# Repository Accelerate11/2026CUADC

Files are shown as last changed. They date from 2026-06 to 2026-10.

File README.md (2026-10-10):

# 2026CUADC
哈尔滨工业大学2026CUADC多旋翼无人机侦察与救援项目组备赛日志

2025年末我接手了航协多旋翼无人机侦察与救援项目组，并开始了在先前基础上的新一轮备赛，记录此文档来做详细的技术路线备份和日志书写，方便后人学习使用，也欢迎各位技术大佬与我联系进行交流和批评指正

2026.8.11  辽宁·沈阳  2026CUADC北部赛区冠军

2026.10.08  四川·自贡  2026CUADC国赛 一机组1338分（国一）  二机组1341分（国一） 团体第四（国三）

感谢CUAV雷迅创新对本项目的大力支持！

感谢micoair微空科技对本项目的大力支持！

感谢HARD海砥装备对本项目的大力支持！

屏幕截图 2026-09-11 192442

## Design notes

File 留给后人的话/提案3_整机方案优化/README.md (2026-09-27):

# 结构方面，参考大连理工大学结构，做非常规构型四旋翼、使用高能量密度高压大容量电池，提升整体续航，将机身结构直接纳入桨保部分，参考这些优秀结构：
屏幕截图 2026-09-27 121436
屏幕截图 2026-09-27 121443
屏幕截图 2026-09-27 121426
屏幕截图 2026-09-27 121419
屏幕截图 2026-09-27 121408
屏幕截图 2026-09-27 121359
# 硬件方面，更换更稳定的4G模块，考虑使用更强的机载算力，有钱或者有资源建议使用orin NX 更新飞控、RTK设备，RTK基站有条件的话买两套，更换大功率数传
# 算法方面，提升代码结构，可以考虑使用Behavior Tree，危险物识别阶段，如果能训练出高速情况下的快速准确识别模型采用视觉模型会更好

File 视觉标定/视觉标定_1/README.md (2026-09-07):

# Vision-Servo Payload Alignment Toolkit

一个面向 ROS 2 的**视觉对准 / 投放中心标定框架**。这个公开版刻意不提供任何目标检测模型，也不绑定 RealSense、YOLO 或某一类视觉算法；核心只保留最有复用价值的部分：

- 把视觉节点输出统一成一个很薄的 ROS 2 接口；
- 把“目标中心准星”和“载荷真实投放中心准星”从视觉算法里拆出来；
- 支持低位铅垂线人工对准，稳健求解每个载荷在 FCU `FRD` 机体系中的有效 `X/Y`；
- 支持高位真实落点试验，用中位数 + MAD 修正静态投放中心；
- 可选保留 MAVROS 舵机地面循环测试。

> 这个仓库的原则是：**视觉节点只负责“我看到了什么、目标在机体系哪里”；准星、人工标定和投放中心几何由独立节点负责。**

## 1. 架构

```text
camera driver / your image source
       │
       ├── sensor_msgs/Image ───────────────┐
       ├── sensor_msgs/CameraInfo ──────────┤
       │                                    │
       ▼                                    ▼
YOUR VISION NODE                    alignment_viewer
(完全由使用者实现)                  绿色：目标中心
       │                             彩色：各载荷投放中心投影
       │ PoseArray / FRD                    │
       └── /vision_servo/targets_body ──────┘
                      │
                      └── 可同时给你自己的飞行/伺服控制节点使用
```

公开版不再包含旧工程中的检测模型、检测器实现和比赛专用全流程状态机。视觉接口和准星显示彻底解耦，因此别人可以直接接自己的 YOLO、传统 CV、AprilTag、深度相机、双目、VIO 或其他目标定位节点。

## 2. ROS 2 视觉接口

默认目标话题：

```text
/vision_servo/targets_body
```

类型：

```text
geometry_msgs/msg/PoseArray
```

约定：

- `header.stamp`：该帧图像的**采集时间**，必须非零；
- `header.frame_id`：默认 `fcu_body_frd`；
- `pose.position.{x,y,z}`：目标参考点在 FCU body FRD 下的位置，单位 m；
- `pose.orientation.x`：目标直径/尺度，可不用，填 `0.0`；
- `pose.orientation.y`：置信度 `[0,1]`，不知道时填 `1.0`；
- `pose.orientation.z`：可选深度诊断值，不用填 `0.0`；
- `pose.orientation.w`：接口版本哨兵，填 `1.0`。

坐标固定使用 FCU/MAVLink `FRD`：

- `+X`：机头前；
- `+Y`：机体右；
- `+Z`：向下。

完整说明见 [`docs/VISION_INTERFACE.md`](docs/VISION_INTERFACE.md)。

## 3. 为什么准星必须独立于视觉节点

原来最有价值的思路并不是某一个检测模型，而是两套几何量同时显示：

1. **目标中心**：视觉节点给出的目标三维位置投影到当前相机画面；
2. **Payload projection**：每个载荷在机体上的标定 `X/Y` 垂线，与当前目标对准平面的交点再投回相机画面。

两者只有在真实载荷投放中心位于目标正上方时才应重合。载荷准星不能从目标 `x/y` 生成，否则准星会“跟着目标跑”，反而把对准误差隐藏掉。

公开版中的 `alignment_viewer` 只依赖：

- 相机图像 + `CameraInfo`；
- `camera -> FCU body FRD` 外参；
- 视觉节点发布的目标 FRD 坐标；
- 每个载荷的 FRD 投放中心。

因此检测算法可以被完全替换。

## 4. 快速开始

环境建议：Ubuntu 22.04 + ROS 2 Humble。

### 4.1 准备配置

```bash
cp config/aircraft.example.yaml config/aircraft.yaml
# 编辑 config/aircraft.yaml
python3 tools/validate_config.py --config config/aircraft.yaml --mode alignment
python3 tools/generate_config.py
```

最关键的配置是：

```yaml
camera:
  image_topic: /camera/color/image_raw
  camera_info_topic: /camera/color/camera_info
  rotation_camera_to_frd: [... 9 values ...]
  translation_frd_m: [x, y, z]

vision:
  detections_topic: /vision_servo/targets_body
  frame_id: fcu_body_frd

payloads:
  release_offsets_frd_m:
    [x1, y1, z1,
     x2, y2, z2]

target:
  # 视觉发布的参考点到真正“对准平面”的竖直高度。
  # 例如视觉发布桶底/地面中心，而桶口高 0.30 m，则填 0.30。
  # 若视觉已经直接发布桶口平面上的 3D 点，则填 0.0。
  height_m: 0.30
```

### 4.2 编译

```bash
./bin/build.sh
```

### 4.3 启动你的相机和视觉节点

公开版**不会替你启动相机，也不会加载任何模型**。先启动你自己的相机节点，再启动你自己的视觉节点，使其持续发布上述 `PoseArray`。

仓库内提供一个空模板：

```bash
./bin/run_vision_template.sh
```

真正接入时通常直接复制 `vision_provider_template.py`，把 `detect_targets_body_frd()` 函数替换成自己的算法即可；如果你已经有独立节点，只要话题格式满足契约，模板完全不用运行。

先检查接口：

```bash
./bin/check_vision_contract.sh
```

### 4.4 启动准星画面

```bash
./bin/visual_alignment.sh
```

画面会显示：

- 绿色十字：视觉目标中心；
- 不同颜色十字：各 Payload 的真实投放中心在当前目标平面上的投影；
- `+X FWD` / `+Y RIGHT`：当前配置对应的机体系方向；
- 每个 Payload 的 `dF / dR` 误差。

本脚本只启动准星显示节点，不启动飞控、不解锁、不飞行。

## 5. 静态投放中心标定

以 Payload 1 为例：

1. 低位固定飞机并保持姿态稳定；
2. 从真实投放机构中心垂下铅垂线；
3. 人工移动整架飞机，让铅垂线落到目标中心；
4. 保持 3 秒以上；
5. 退出 `visual_alignment.sh`；
6. 使用这一轮自动保存的检测 CSV：

```bash
python3 tools/estimate_static_offsets.py \
  logs/static_alignment_YYYYMMDD_HHMMSS/detections.csv \
  --payload 1 \
  --aircraft config/aircraft.yaml \
  --last-seconds 3 \
  --write
```

脚本用最近稳定窗口的 FRD `X/Y` 中位数作为该载荷的静态投放中心，**不会修改 Z**。Z 仍应由机械测量获得。

然后重新生成准星参数：

```bash
python3 tools/generate_config.py
```

对 Payload 2 重复一次。

## 6. 高位真实落点修正

静态几何不能覆盖舵机释放延迟、瓶体摆动、残余水平速度、气流等误差。真实投放后按 FRD 方向记录第一落点相对目标中心的偏差：

```bash
python3 tools/record_drop_trial.py \
  --payload 1 \
  --height 0.8 \
  --miss-forward 0.03 \
  --miss-right -0.02 \
  --output logs/drop_trials.csv
```

每个载荷、每个最终使用高度建议至少 3 次，再求解：

```bash
python3 tools/solve_drop_trials.py \
  logs/drop_trials.csv \
  --aircraft config/aircraft.yaml \
  --output logs/drop_solution.yaml
```

规则：

```text
recommended XY = static XY + median landing miss XY
```

同时输出 MAD 作为重复性指标。

## 7. 舵机地面检查（可选）

如果你仍使用 MAVROS/ArduPilot，并在 `aircraft.yaml` 中填写了 FCU 与舵机参数，可在**卸桨、飞控未解锁**状态运行：

```bash
./bin/servo_ground_check.sh
```

这部分与准星/视觉接口相互独立，不需要使用。

## 8. 目录

```text
config/
  aircraft.example.yaml       用户唯一需要维护的物理/话题配置模板
  alignment_base.yaml         准星节点基础参数
bin/
  build.sh                    编译 ROS 2 工作区
  visual_alignment.sh         只启动独立准星节点
  run_vision_template.sh      启动“空视觉节点”模板
  check_vision_contract.sh    检查别人接入的视觉节点是否满足接口
  servo_ground_check.sh       可选 MAVROS 舵机地面测试
tools/
  generate_config.py
  validate_config.py
  estimate_static_offsets.py
  record_drop_trial.py
  solve_drop_trials.py
  servo_cycle_test.py
ros2_ws/src/vision_servo_calibration/
  vision_servo_calibration/alignment_viewer_node.py
  vision_servo_calibration/vision_provider_template.py
  vision_servo_calibration/vision_contract_check.py
  vision_servo_calibration/projection.py
  launch/alignment.launch.py
docs/
  VISION_INTERFACE.md
  DESIGN.md
  MIGRATION_FROM_OLD_WORKSPACE.md
```

## 9. 发布到 GitHub 前

`.gitignore` 已排除：

- `build/install/log`；
- `config/aircraft.yaml`；
- 生成参数；
- 飞行/标定日志；
- Python 缓存。

这个公开版也已经移除原始检测模型、ONNX/PT 文件、原视觉算法和比赛专用全流程节点。请在正式发布前自行选择并写入开源许可证；本整理版没有替项目作者擅自改变许可证。

## 10. 安全边界

本仓库的核心功能是**测量、可视化和标定**。任何自动飞行、自动投放、舵机动作都应由使用者自己的飞行控制程序承担，并自行设置硬件急停、围栏、人工接管和测试流程。

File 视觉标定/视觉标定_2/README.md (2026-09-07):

# CUADC D435i 双投放中心标定工具包

面向当前 CUADC V6X + D435i + ROS 2 Humble 工作空间的**视觉中心 / 双投放口准星标定包**。

本包保留三种可视化方案：

1. **网页模式（推荐 SSH 场景）**：标定画面发布为 ROS Image，经 `web_video_server` + SSH 端口转发，在 Windows/Linux 浏览器查看；
2. **本地显示器模式**：NUC 接显示器时，用独立 `alignment_viewer` 的 OpenCV 窗口或 `rqt_image_view` 查看；
3. **直接视觉节点叠加模式**：当前 `drop_bucket_realsense_node.py` 直接发布 `/cuadc/calib/annotated`，绿色 TARGET + P1/P2 准星与正式识别结果完全同源。

> 安全要求：整个静态标定过程必须卸桨、不解锁、不启动自主飞行状态机。标定只涉及相机、视觉节点和静态机械几何。

---

## 1. 当前坐标系

正式视觉节点使用机体 **FLU**：

```text
+X = 机头前方
+Y = 飞机左侧
+Z = 飞机上方
```

D435i 当前安装方向对应：

```text
图像左边 = 飞机前方
图像右边 = 飞机后方
图像上边 = 飞机右侧
图像下边 = 飞机左侧
相机光轴 = 向下
```

独立 `alignment_viewer` 使用 **FRD**：

```text
+X = 机头前方
+Y = 飞机右侧
+Z = 向下
```

FLU 与 FRD 转换：

```text
X_frd =  X_flu
Y_frd = -Y_flu
Z_frd = -Z_flu
```

---

## 2. 本机当前采用的标定值

当前打包版本记录的是 2026-09-07 这一架 V6X 的候选正式值：

### 相机视觉外参（FLU）

```yaml
camera_offset_body_m: [0.0, 0.0, -0.35]
camera_xy_calib_bias_m: [0.047805, -0.014577]
camera_optical_to_body_rotation:
  [-0.971358, 0.237622, 0.0,
    0.237622, 0.971358, 0.0,
    0.0,      0.0,     -1.0]
```

旋转矩阵行列式应保持约 `+1.000`。

### 双投放口（FLU）

```text
P1 / SERVO9
[+0.0260, -0.0650, -0.3200] m
= 前 2.60 cm、右 6.50 cm、下 32 cm

P2 / SERVO10
[+0.0109, +0.0720, -0.3200] m
= 前 1.09 cm、左 7.20 cm、下 32 cm
```

### 正式投放工作高度

```text
SEARCH        2.2 m
ALIGN_COARSE  1.7 m
ALIGN_FINE    1.3 m
RELEASE       1.3 m
```

> P2 是当前最新候选值。重新拆装相机、投放机构、机架或飞控后必须重新验证。

机器可读记录：`config/cuadc_v6x_current_calibration.yaml`。

---

## 3. 目录结构

```text
README.md
config/
  cuadc_v6x_current_calibration.yaml   当前本机 FLU/FRD 标定记录
  aircraft.example.yaml                通用模板
  aircraft.cuadc_v6x_current.yaml      独立 viewer 的当前 FRD 配置
  alignment_base.yaml
bin/
  build.sh                              编译独立 viewer
  visual_alignment.sh                  原独立 viewer
  visual_alignment_display.sh          本地显示器模式
  visual_alignment_headless.sh         无显示器发布 annotated Image
  web_video_server.sh                  网页视频服务器
  show_annotated_local.sh              rqt_image_view 本地查看
  check_cuadc_calibration_topics.sh     检查 ROS 标定话题
  stop_calibration_helpers.sh           停止辅助进程
  run_current_cuadc_visual_calibration.sh 当前 CUADC 视觉节点标定启动模板
tools/
  sample_payload_xy.py                 5 秒中位数/MAD/剩余误差采样
  apply_current_cuadc_calibration.py   将当前值写入 cuadc_mission
  verify_current_workspace.py          检查工作空间正式值
docs/
  QUICKSTART_CUADC.md
  WEB_VISUALIZATION.md
  DISPLAY_VISUALIZATION.md
  CUADC_VISUAL_NODE_INTEGRATION.md
  COORDINATE_SYSTEMS.md
  CALIBRATION_RECORD_2026_09_07.md
  TROUBLESHOOTING.md
ros2_ws/src/vision_servo_calibration/
  ...                                  独立准星 viewer 源码
```

---

## 4. 推荐方案：当前 CUADC 视觉节点直接叠加 + 网页查看

这是当前无显示器、SSH 使用场景最方便的方案。

### 4.1 安装依赖

```bash
sudo apt update
sudo apt install -y \
  ros-humble-cv-bridge \
  ros-humble-image-transport \
  ros-humble-web-video-server \
  ros-humble-rqt-image-view \
  python3-opencv \
  python3-numpy \
  python3-yaml
```

### 4.2 启动当前视觉标定节点

把本包放到例如：

```text
~/cuadc_mission/calibration/cuadc_d435i_payload_calibration_2026_09_07
```

然后：

```bash
cd ~/cuadc_mission/calibration/cuadc_d435i_payload_calibration_2026_09_07
chmod +x bin/*.sh tools/*.py
./bin/run_current_cuadc_visual_calibration.sh ~/cuadc_mission
```

该脚本使用当前记录的：

- `camera_xy_calib_bias_m`
- `camera_optical_to_body_rotation`
- P1/P2
- 自动曝光
- `/cuadc/calib/annotated`

不会启动状态机，不会启动 MAVROS。

### 4.3 检查标定画面话题

新 SSH 终端：

```bash
cd ~/cuadc_mission/calibration/cuadc_d435i_payload_calibration_2026_09_07
./bin/check_cuadc_calibration_topics.sh
```

至少应看到：

```text
/perception/drop_buckets_body
/cuadc/calib/annotated
```

若已启用完整旁路，还可看到：

```text
/cuadc/calib/color/image_raw
/cuadc/calib/color/camera_info
/vision_servo/targets_body
```

---

## 5. 网页模式（SSH / NUC 无显示器）

### NUC 端

```bash
cd ~/cuadc_mission/calibration/cuadc_d435i_payload_calibration_2026_09_07
./bin/web_video_server.sh
```

默认端口 `8080`。如果 8080 已经被旧的 `web_video_server` 占用，脚本会提示并复用，不要重复启动。

### Windows CMD 端

先获得 NUC 实际 IP：

```bash
hostname -I
```

Windows **CMD** 中必须写一整行，不能用 Linux 的 `\` 换行：

```cmd
ssh -L 8080:127.0.0.1:8080 cuadc@NUC实际IP
```

保持该 CMD 窗口不关闭。

浏览器打开：

```text
http://127.0.0.1:8080/stream?topic=/cuadc/calib/annotated&type=mjpeg
```

画面含义：

```text
绿色 TARGET      = 正式视觉最终输出的桶中心
红/橙 P1         = 1号 / SERVO9 投放口准星
黄/紫 P2         = 2号 / SERVO10 投放口准星
FWD              = 飞机前方
RIGHT            = 飞机右侧
```

---

## 6. 本地显示器模式

NUC 接显示器且有桌面环境时，有两种方式。

### 方式 A：直接查看 `/cuadc/calib/annotated`

```bash
./bin/show_annotated_local.sh
```

底层使用 `rqt_image_view`。

### 方式 B：独立 `alignment_viewer`

先编译：

```bash
./bin/build.sh
```

生成当前 FRD 配置：

```bash
cp config/aircraft.cuadc_v6x_current.yaml config/aircraft.yaml
python3 tools/validate_config.py --config config/aircraft.yaml --mode alignment
python3 tools/generate_config.py
```

然后：

```bash
./bin/visual_alignment_display.sh
```

独立 viewer 会显示：

- 绿色：视觉目标；
- 各 Payload 彩色准星；
- `dF / dR`；
- `+X FWD / +Y RIGHT`；
- 自动记录 CSV 和标注视频。

---

## 7. 无显示器独立 viewer + 网页

如果不想在正式视觉节点里画准星，也可以让独立 viewer 生成：

```text
/vision_servo/alignment/image
```

步骤：

```bash
./bin/visual_alignment_headless.sh
./bin/web_video_server.sh
```

浏览器：

```text
http://127.0.0.1:8080/stream?topic=/vision_servo/alignment/image&type=mjpeg
```

此模式要求视觉侧已经发布：

```text
/cuadc/calib/color/image_raw
/cuadc/calib/color/camera_info
/vision_servo/targets_body
```

详见 `docs/CUADC_VISUAL_NODE_INTEGRATION.md`。

---

## 8. 静态 P1/P2 标定流程

### 8.1 机械条件

- 卸桨；
- 飞机保持水平；
- 正式投放高度建议直接在 `1.3 m` 工作高度验证；
- 桶口高度与比赛桶一致；
- 用铅垂线确定舵机/释放机构真实中轴线。

### 8.2 P1

把桶中心放在 P1 / SERVO9 实际中轴线正下方。

当前 P1 真值：

```text
FLU x=+0.0260 y=-0.0650
```

采样：

```bash
python3 tools/sample_payload_xy.py \
  --payload 1 \
  --true-x 0.0260 \
  --true-y -0.0650 \
  --duration 5
```

输出：

```text
median FLU
MAD
remaining dx
remaining dy
```

目标：

```text
|remaining dx| <= 0.005 m
|remaining dy| <= 0.005 m
```

### 8.3 P2

桶移到 P2 / SERVO10 实际中轴线正下方。

当前候选：

```text
FLU x=+0.0109 y=+0.0720
```

```bash
python3 tools/sample_payload_xy.py \
  --payload 2 \
  --true-x 0.0109 \
  --true-y 0.0720 \
  --duration 5
```

同样建议控制在 5 mm 内；如果已经达到 3~5 mm，停止继续追 1 mm 级噪声。

---

## 9. 如何判断应该调什么

### P1/P2 同方向、近似相同偏差

优先调：

```text
camera_xy_calib_bias_m
```

说明更像相机整体 XY 平移误差。

### P1 与 P2 呈明显相反方向残差

优先检查：

```text
camera_optical_to_body_rotation 的 yaw
```

也要重新核对两个机械中轴线。

### P1 很准，P2 单独不准

不要继续破坏已经正确的相机外参，优先修：

```text
P2 payload_release_offsets_body_m
```

这正是当前这架飞机最后一次调整采用的策略。

### Z 不准

先检查：

```text
飞机参考点高度
桶口真实高度
camera_offset_body_m[2]
depth_reference_mode
```

当前 `rim_direct` 模式下，视觉输出参考点已经是桶沿/桶口平面，不应额外再加 0.30 m。

---

## 10. 把当前标定写入正式 `cuadc_mission`

先预览：

```bash
python3 tools/apply_current_cuadc_calibration.py \
  --workspace ~/cuadc_mission \
  --dry-run
```

确认无误后：

```bash
python3 tools/apply_current_cuadc_calibration.py \
  --workspace ~/cuadc_mission
```

然后检查：

```bash
python3 tools/verify_current_workspace.py \
  --workspace ~/cuadc_mission
```

最后重新编译：

```bash
cd ~/cuadc_mission
source /opt/ros/humble/setup.bash
colcon build --symlink-install --packages-select cuadc_visual_drop_flight
```

---

## 11. 常见问题

### `AMENT_TRACE_SETUP_FILES: unbound variable`

本包脚本已经在 `source setup.bash` 前暂时 `set +u`，不会再因为 ROS 2 setup 中未定义变量退出。

### `Device or resource busy`

D435i 被旧进程占用：

```bash
pgrep -af "drop_bucket_realsense|realsense2_camera|vision_provider_template"
sudo fuser -v /dev/video* 2>/dev/null
```

停止旧视觉：

```bash
pkill -TERM -f drop_bucket_realsense_node.py 2>/dev/null || true
pkill -TERM -f realsense2_camera 2>/dev/null || true
sleep 2
```

不要同时启动第二个 RealSense driver。

### `bind: Address already in use 0.0.0.0:8080`

通常说明旧 `web_video_server` 已经在运行：

```bash
pgrep -af web_video_server
ss -lntp | grep ':8080'
```

直接复用即可。

### 网页有服务器但没画面

```bash
ros2 topic hz /cuadc/calib/annotated
```

先确认 ROS Image 确实持续发布。

更多见 `docs/TROUBLESHOOTING.md`。

---

## 12. 标定原则

1. **准星不能跟着目标生成**：P1/P2 必须来自机械投放口外参；
2. **图像和目标必须同一采集时间戳**：当前视觉使用 `capture_stamp`，应保留；
3. **相机只允许一个进程占用**；
4. **正式视觉接口与标定可视化解耦**；
5. 优先在最终工作高度验证；
6. P1 已正确时，不要为了修 P2 再破坏全局相机外参；
7. 参数最终写入 `flight_params.yaml` 和状态机前必须重新静态验证。

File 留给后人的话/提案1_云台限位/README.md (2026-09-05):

# AKPF 两轴无人机水平云台

这是一个可落地验证的两轴（Roll/Pitch）水平云台草案。云台挂在无人机下方，控制器读取安装在相机托架上的 ICM-42688-P IMU，驱动两个位置舵机，使托架相对地面保持水平。飞控使用 CUAV，机载计算机使用 Intel NUC；稳定闭环完全运行在 STM32 上，飞控或 NUC 暂时掉线时仍可工作。

## 选型

- 控制器：NUCLEO-G431RB（STM32G431RBT6，170 MHz Cortex-M4F）
- 云台 IMU：ICM-42688-P SPI 模块，必须使用 3.3 V 逻辑
- 执行器：2 个金属齿数字舵机，建议 7.4 V、响应时间不大于 0.12 s/60°、堵转扭矩按载荷留 2 倍以上裕量
- 舵机电源：独立 5～8.4 V BEC，建议持续 5 A 以上；BEC GND、STM32 GND、IMU GND 共地
- 上位机接口：NUCLEO 板载 ST-LINK 虚拟串口，115200 8N1，连接 Intel NUC

> 重要：普通位置舵机存在齿隙、死区和低刷新率，本方案适合“保持水平/低频扰动”的原型。若要求航拍级隔振和快速姿态补偿，应换成带编码器的无刷云台电机与 FOC 驱动，控制软件架构仍可复用，但执行器控制层需要替换。

## 工程结构

```text
firmware/                  STM32 PlatformIO 固件
  include/                 驱动、滤波、控制、协议接口
  src/                     固件实现
  test/                    可在 PC 上跑的算法单元测试
tools/                     Intel NUC 串口命令与日志工具
docs/architecture.md       坐标系、控制环与安全状态机
docs/hardware.md           接线、电源和机械要求
docs/commissioning.md      台架到实机的分阶段调试方案
docs/protocol.md           NUC 与 MCU 文本协议
```

## 快速开始

1. 按 [硬件接线](docs/hardware.md) 接 IMU，暂时不要安装舵臂。
2. 安装 VS Code + PlatformIO，或直接安装 PlatformIO Core。
3. 在 `firmware` 目录执行：

   ```powershell
   platformio run
   platformio run --target upload
   ```

4. NUC/PC 安装串口工具依赖并查看状态：

   ```bash
   python3 -m pip install -r tools/requirements.txt
   python3 tools/gimbal_cli.py --port /dev/ttyACM0 status
   python3 tools/gimbal_cli.py --port /dev/ttyACM0 monitor
   ```

5. 上电后保持云台托架静止约 2 秒。看到 `READY` 后，用 `ARM` 才会进入稳定状态。正式装舵臂前先用示波器或舵机测试仪确认脉宽和方向。

## 当前版本的边界

- 两个转轴必须近似正交，默认 Roll 为外框、Pitch 为内框。
- 航向不稳定，随无人机机体转动。
- 加速度计只能观测重力方向；持续水平加速会产生短时倾角误差。滤波器会在加速度模长偏离 1 g 时降低加速度修正权重。
- 默认最大机械行程为中心点两侧 45°。必须根据实际机构修改 `firmware/include/app_config.h` 中的脉宽、方向和角度限位。
- 当前校准保存在 RAM；断电后需要重新做陀螺零偏校准。安装误差可通过 `ZERO` 临时归零，量产版建议保存到 MCU Flash。

## 验收目标（建议）

- 静态水平误差：Roll/Pitch 均小于 1.0°
- 输入 ±20°、频率 0.5 Hz 的台架扰动：RMS 误差小于 2.0°
- IMU 通信连续失败 10 次：保持最后安全舵机位置并退出 ARMED
- 串口断开：不影响本地稳定闭环

设计依据与后续升级路径见 [系统架构](docs/architecture.md)，完整操作见 [调试方案](docs/commissioning.md)。

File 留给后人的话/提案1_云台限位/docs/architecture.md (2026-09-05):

# 系统架构与控制草案

## 1. 分工

```text
 CUAV 飞控 ──MAVLink/USB或串口── Intel NUC
                                      │
                                      │ USB VCP：命令、状态、日志
                                      ▼
                           STM32G431 云台控制器
                             │ SPI          │ PWM
                             ▼              ▼
                    托架 ICM-42688-P    Roll/Pitch 舵机
                             ▲              │
                             └──机械姿态─────┘
```

- STM32：500 Hz 读取云台 IMU、估计 Roll/Pitch、运行姿态—角速度串级控制并产生舵机 PWM。
- CUAV：只负责飞行控制，不参与云台的基本稳定闭环。
- Intel NUC：设置期望角、使能/停用、记录 CUAV 与云台姿态、计算性能指标。NUC 死机或 MAVLink 断开不会破坏已经运行的本地闭环。

第一版不直接使用 CUAV 姿态做前馈。这样更容易把传感器安装、舵机方向和反馈稳定性分别验证。完成本地闭环后，可由 NUC 将 CUAV 的 Roll/Pitch 以 50～100 Hz 发给 MCU，作为舵机位置前馈，本地 IMU 只修正残差；这是后续版本而不是首次上电功能。

## 2. 坐标与机构假设

- Roll 为外框，Pitch 为内框，两个转轴正交。
- IMU 固定在最终承载相机/载荷的内框，而不是固定在无人机机身。
- 当前滤波公式要求静止水平时 `AX≈0, AY≈0, AZ≈+1 g`。
- 绕 IMU X 轴的正角速度视作 Roll 正方向，绕 Y 轴的正角速度视作 Pitch 正方向。
- `kRollServoDirection=+1` 的含义是舵机命令角增大时，IMU 的 Roll 正角速度增大；Pitch 同理。这个符号必须实测。

若 IMU 只能旋转 90° 安装，不要仅凭感觉改滤波公式。先将传感器六面静置记录数据，建立从传感器坐标到托架坐标的带符号置换矩阵，再应用到 `Icm42688::read()` 输出。

## 3. 控制算法

### 姿态估计

当前版本使用带动态加速度抑制的互补滤波：

1. 陀螺角速度积分得到短期姿态；
2. 加速度方向得到低频重力倾角；
3. 当加速度模长偏离 1 g 时，自动减小加速度校正权重。

这是两轴水平控制的可调试基线。持续水平加速时仍会把一部分线加速度误认为倾斜。飞行数据表明该误差不可接受时，再升级为四元数 Mahony/EKF，并引入 CUAV 姿态或载荷运动模型。

### 控制器

每个轴采用离散串级结构：

```text
角度误差 ──K_att──> 目标角速度(限幅)
目标角速度 - 实测角速度 ──K_rate──> 舵机角速度(限幅)
舵机角速度积分 ──> 位置舵机命令(机械限位)
```

对位置舵机使用“命令角速度积分”很重要：托架已经水平时，积分后的舵机位置会保持抵消机身倾角所需的值，不会突然回中。所有输出同时受舵机角度和变化率限制。

默认参数只是安全起调值，不是飞行参数：

- `attitude_kp = 4.0 s⁻¹`
- `rate_kp = 1.2`
- 最大目标角速度 `120 deg/s`
- 最大舵机命令变化率 `160 deg/s`

## 4. 状态机与失效保护

- `BOOT`：外设初始化。
- `CALIBRATING`：连续采集 1000 个静止样本计算陀螺零偏；检测到运动就重新计数。
- `READY`：已校准、舵机保持当前位置，但控制器不更新。
- `ARMED`：运行稳定闭环。
- `FAULT`：IMU 初始化失败或连续读取失败达到 10 次。舵机保持最后位置，禁止重新 ARM，需排故后重启。

串口断线不触发失效，因为基本闭环不依赖串口。机械碰限位、舵机过流与 BEC 欠压目前无法由软件直接检测；实机版应增加电流/电压采样，并为每个轴增加限位裕量或绝对编码器。

## 5. 设计升级路线

1. 台架版：位置舵机 + 云台 IMU，本工程当前状态。
2. 飞行验证版：保存校准到 Flash、独立硬件看门狗、BEC 电压监控、CUAV 姿态前馈。
3. 航拍版：无刷云台电机、磁编码器/高分辨率角度传感器、电流环 FOC、机械减振与在线陷波器。

器件资料：[ICM-42688-P 官方页面](https://www.invensense.tdk.com/en-us/products/consumer/icm-42688-p)、[NUCLEO-G431RB 官方页面](https://www.st.com/en/evaluation-tools/nucleo-g431rb.html)、[MAVLink Common 消息集](https://mavlink.io/en/messages/common.html)。

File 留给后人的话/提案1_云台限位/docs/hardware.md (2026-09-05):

# 硬件、接线与供电

## 1. NUCLEO-G431RB 引脚

| 功能 | STM32 引脚 | Nucleo 标识 | 连接 |
|---|---:|---:|---|
| ICM SPI SCK | PA5 | D13 | IMU SCLK |
| ICM SPI MISO | PA6 | D12 | IMU SDO |
| ICM SPI MOSI | PA7 | D11 | IMU SDI |
| ICM SPI CS | PB6 | D10 | IMU nCS |
| Roll PWM | PA0 / TIM2_CH1 | A0 | Roll 舵机信号 |
| Pitch PWM | PA1 / TIM2_CH2 | A1 | Pitch 舵机信号 |
| 调试 UART TX | PA2 / LPUART1_TX | 板载 VCP | 到 NUC USB |
| 调试 UART RX | PA3 / LPUART1_RX | 板载 VCP | 从 NUC USB |
| IMU 电源 | 3V3 | 3V3 | IMU VCC（确认模块无 5 V 要求） |
| 公共地 | GND | GND | IMU、BEC、两舵机共地 |

PA5 同时连接 Nucleo 用户 LED，SPI 时 LED 可能发暗光，这是正常现象。若具体扩展板在 PA5 上有较重负载，改用另一组 SPI 引脚并同步修改固件。

## 2. 电源拓扑

```text
无人机电池
  ├─> 飞控电源模块 ─> CUAV
  ├─> NUC 稳压电源  ─> Intel NUC
  └─> 独立 BEC 5~8.4 V ─┬─> Roll 舵机 V+
                         └─> Pitch 舵机 V+

BEC GND ─ STM32 GND ─ IMU GND ─ CUAV/NUC 接口地（单点/低阻连接）
```

禁止从 Nucleo 5 V 引脚给两个舵机供电。舵机启动和堵转电流会导致 MCU 复位、IMU 毛刺甚至烧毁 USB 端口。BEC 输出电压必须落在舵机额定范围内，靠近舵机电源分支放置低 ESR 470～1000 µF 电解电容和 0.1 µF 陶瓷电容。

初次上电使用带电流限制的台式电源，限流从 0.5 A 起，仅接控制板和 IMU；接舵机后根据铭牌逐步放宽。确认所有地线连接后再接 PWM 信号。

## 3. 机械要求

- 先做静态配平：断电时相机托架在各轴不应明显自行坠落。配平差会直接变成舵机持续电流和发热。
- IMU 要刚性固定在内框，远离舵机齿轮冲击和 BEC 电感；不要把 IMU 装在软泡棉上造成相位滞后。
- 无人机与云台之间可做整体减振，但控制用 IMU 与被控载荷之间必须刚性连接。
- 两轴全行程手动转动，确认线束不会拉扯、卡住或进入桨叶区域。
- 软件默认只允许 ±45°，机械上仍需保留至少 5° 裕量。

## 4. CUAV 与 NUC

推荐 CUAV 通过独立 USB 或隔离/正确电平的 TELEM UART 接 NUC，STM32 Nucleo 通过板载 ST-LINK USB 接 NUC。不要把 CUAV 的 5 V UART 电源与 BEC 输出硬并联。若使用裸 UART：先核对具体 CUAV 型号端口是否为 3.3 V TTL，TX/RX 交叉并共地。

NUC 同时会看到两个设备，例如：

- `/dev/ttyACM0`：NUCLEO 虚拟串口
- `/dev/ttyACM1` 或 `/dev/ttyUSB0`：CUAV MAVLink

用 `/dev/serial/by-id/` 的稳定设备名部署，避免重启后 ACM 编号互换。

NUCLEO-G431RB 默认焊桥把 ST-LINK VCP 接到 LPUART1 的 PA2/PA3，本工程按该默认配置编写。若板卡焊桥已被改到 USART1 PC4/PC5，需恢复默认焊桥或同步修改 `main.cpp` 的 UART 实例、GPIO 复用和中断入口。

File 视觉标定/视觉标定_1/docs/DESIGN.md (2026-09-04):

# Design Notes

## 1. 解耦边界

公开版把原先单个“大视觉节点”的职责拆成三层：

1. **Camera / image source**：只负责标准图像和 CameraInfo；
2. **Vision Provider**：只负责目标识别和 3D 目标坐标；
3. **Alignment Viewer**：只负责几何投影、准星、人工标定日志。

这样目标识别网络和准星逻辑不会互相污染。

## 2. 两个准星的几何意义

目标准星：

```text
pixel_target = project(body_to_camera(target_body))
```

Payload 准星：

```text
plane_z = target_body.z - target_height
payload_plane_body = [payload_offset.x, payload_offset.y, plane_z]
pixel_payload = project(body_to_camera(payload_plane_body))
```

关键约束是 `payload_plane_body.x/y` 始终来自**飞机固有标定值**，不能来自目标检测值。

## 3. 静态标定为什么可以直接取目标 FRD X/Y

人工用铅垂线把真实 Payload 投放点压到目标中心时，从飞机坐标系观察，目标的 `X/Y` 就等于真实 Payload 垂线的 `X/Y`。因此只要机体稳定，多个视觉样本的目标 `X/Y` 中位数就是新的 Payload 静态偏移。

这一步只识别水平位置，`Z` 仍属于机械几何测量。

## 4. 为什么用中位数而不是单帧

单帧视觉容易受深度噪声、检测框抖动和像素量化影响。静态标定工具取时间窗口内 `X/Y` 中位数，并报告 IQR；真实落点工具也用中位数和 MAD，避免少量异常试投主导参数。

## 5. 为什么不用 TF 强绑定

为了让其他人接入最少依赖，公开版不要求把相机外参发布进 TF 树。准星节点直接读取一组经过验证的 `camera -> body FRD` 旋转和平移。如果项目已有完整 TF，也可以在自己的视觉节点中完成变换后按契约发布 FRD。

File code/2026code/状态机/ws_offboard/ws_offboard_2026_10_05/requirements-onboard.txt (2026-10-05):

# 原部署使用的 Intel NUC11 CPU 运行依赖。
ultralytics==8.4.41
onnx==1.17.0
onnxruntime==1.23.2
PyYAML>=6.0,<7.0
Pillow>=10.0,<12.0

# 以下厂商和运行环境依赖需要预先准备，不由此清单安装：
# - NumPy 版本需满足 >=1.24,<2.0。
# - cv2 / OpenCV 使用机载镜像或团队认可的 Jetson 构建。
# - 原环境使用 PyTorch 2.11 的 CPU 构建。
# - pyrealsense2 / librealsense 需与安装的 D435i 一起验证。
# - rclpy 来自 /opt/ros/humble 的 ROS 2 Humble 安装。

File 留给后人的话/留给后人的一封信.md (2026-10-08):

# 2025留给后人的话

## 1. 解决起飞偏移问题

可从以下两个方向进行改进：

- 使用外置罗盘
- 使用双 RTK 定向

## 2. 提升视觉识别效率

- 视觉识别部分考虑采用**多圆识别**方法，提高整体识别效率。

## 3. 优化结构设计

- 结构连接件建议改为**两部分可拆卸结构**。
- 提高装配、拆卸、维护和运输的便利性。

## 4. 重点解决信号传输问题

重点关注飞行过程中各类无线及有线信号的稳定性，包括但不限于：

- 数传干扰
- 网络波动
- 路由器信号稳定性
- RTK 信号稳定性
- 机载电脑回传稳定性

上述问题可能影响：

- RTK 定位与定向
- 飞控数据传输
- 机载电脑与地面端通信
- 实时图像及状态信息回传

可考虑引入 **4G 模块**，作为通信链路的补充或冗余方案，提高整体通信稳定性。

## 5. 优化验证方式

- 部分代码可使用**小飞机在室内进行验证**。
- 减少大型无人机反复测试带来的时间成本。
- 降低场地需求和测试成本。
- 提高代码调试与功能验证效率。

## 6. 提升飞行器本体控制效果

目前主要采用基础 PID 控制，后续可进一步研究其他控制方法，提高飞行控制效果，例如：

- PID 参数进一步优化
- 串级 PID
- 前馈控制
- 自适应控制
- LQR 控制
- MPC 模型预测控制
- 抗扰控制

重点提升：

- 定点悬停精度
- 抗风能力
- 轨迹跟踪精度
- 起飞与降落稳定性
- 外部扰动下的控制鲁棒性

# 2026留给后人的话

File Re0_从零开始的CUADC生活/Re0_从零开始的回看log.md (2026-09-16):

# ArduPilot 飞行日志（Log）基础阅读教程

> 适合：第一次使用 Mission Planner / Log Browser 看日志的人  
> 目标：能看懂最常用的曲线，并能初步判断振动、姿态跟踪、电机输出、PID 和 EKF 是否有明显问题。

---

# 1. Log 是什么

飞控运行时会不断记录数据，日志就相当于无人机的“黑匣子”。

里面会记录：

- 姿态
- 角速度
- PID
- 电机输出
- IMU 振动
- GPS
- 气压计
- 磁罗盘
- EKF
- 电池
- 报错和飞行事件

所以飞机出现问题后，不要只凭“看起来很抖”判断，而是应该：

```text
现象
 ↓
打开 Log
 ↓
找到对应曲线
 ↓
看谁先变化
 ↓
判断原因
```

---

# 2. 怎么打开日志

Mission Planner 中一般可以：

```text
DataFlash Logs
  ↓
Review a Log
  ↓
选择 .BIN 或 .log
```

打开 Log Browser 后，右边会看到很多项目，例如：

```text
ATT
RATE
PIDR
PIDP
PIDY
RCOU
VIBE
GPS
BARO
MAG
XKF
BAT
RCIN
CTUN
```

初学阶段不用全部学。

优先学会：

```text
VIBE
RCOU
RATE
ATT
PIDR / PIDP / PIDY
BAT
GPS
ERR / MSG / Events
```

---

# 3. 看 Log 的三个基本原则

## 3.1 一次不要画太多曲线

错误：

```text
一次勾十几二十条
```

正确：

```text
一次只看 2～6 条
```

例如：

```text
RATE.RDes
RATE.R
```

或者：

```text
RCOU.C1
RCOU.C2
RCOU.C3
RCOU.C4
```

---

## 3.2 最重要的是“目标”和“实际”

控制系统最重要的问题就是：

```text
我想让飞机怎么动？
实际飞机怎么动？
```

例如 Roll：

```text
RATE.RDes = 目标 Roll 角速度
RATE.R    = 实际 Roll 角速度
```

Pitch：

```text
RATE.PDes
RATE.P
```

Yaw：

```text
RATE.YDes
RATE.Y
```

最基本判断：

```text
目标 ≈ 实际
```

---

## 3.3 先看机械，再看 PID

建议顺序：

```text
VIBE
 ↓
RCOU
 ↓
RATE
 ↓
ATT
 ↓
PID
 ↓
EKF
```

如果机械振动已经很大，PID 曲线也会被污染。

---

# 4. X、Y、Z 是什么

机体系可以先简单理解为：

```text
X：前后
Y：左右
Z：上下
```

所以：

```text
VibeX
VibeY
VibeZ
```

表示飞控在三个方向测到的振动。

注意：

```text
VibeX 很大
```

不等于：

```text
前面的电机坏了
```

因为振动会通过机架传播。

---

# 5. 第一项：VIBE

右边找到：

```text
VIBE
 ├─ VibeX
 ├─ VibeY
 ├─ VibeZ
 └─ Clip
```

---

## 5.1 VibeX / Y / Z 怎么看

可以先粗略这样理解：

```text
< 10 m/s²       很好
10～15 m/s²     比较健康
15～30 m/s²     偏高
> 30 m/s²       需要排查
> 60 m/s²       很严重
```

不要只看 Max。

要看是否持续。

例如：

```text
正常：

5 ─────6─────5─────

异常：

10 ─70────75────80────20
```

后一种很像某个转速段发生了结构共振。

---

## 5.2 Clip 是什么

`Clip` 可以理解成：

```text
IMU 被震到超出加速度计量程的累计次数
```

理想：

```text
Clip = 0
```

如果看到：

```text
0
1
5
30
100
```

说明已经发生 clipping。

这时候优先处理机械结构，而不是继续精调 PID。

---

## 5.3 多颗 IMU 怎么看

可能会看到：

```text
VIBE[0]
VIBE[1]
VIBE[2]
```

如果两颗 IMU 在同一个时间同时变高：

```text
IMU0 ↑
IMU1 ↑
```

通常说明这是真实整机振动。

---

# 6. 第二项：RCOU

找到：

```text
RCOU
 ├─ C1
 ├─ C2
 ├─ C3
 ├─ C4
 ...
```

它表示飞控给各个输出通道的命令。

四旋翼通常先看：

```text
C1
C2
C3
C4
```

---

## 6.1 正常情况

例如：

```text
C1 1300
C2 1320
C3 1290
C4 1310
```

说明四个电机总体比较接近。

---

## 6.2 某个电机长期明显更高

例如：

```text
C1 1250
C2 1280
C3 1500
C4 1260
```

可能检查：

- 重心偏移
- 电机推力不一致
- 桨效率不同
- 电调差异
- 电机安装角
- 姿态控制长期纠偏

---

## 6.3 电机触底 / 触顶

如果某一路长期接近最低允许输出：

```text
不能再降了
```

如果长期接近最大输出：

```text
不能再升了
```

这两种都说明：

```text
控制余量不足
```

这时继续加 PID 增益不一定有意义。

---

# 7. 第三项：RATE

RATE 是判断姿态内环最重要的数据之一。

里面常见：

```text
RDes
R
PDes
P
YDes
Y
ROut
POut
YOut
```

其中：

```text
R = Roll
P = Pitch
Y = Yaw
```

---

# 8. Roll RATE 怎么看

只画：

```text
RATE.RDes
RATE.R
```

其中：

```text
RDes = 目标横滚角速度
R    = 实际横滚角速度
```

好的情况：

```text
目标： ───╭────╮────
实际： ───╭────╮────
```

两条尽量接近。

---

## 8.1 实际跟不上

```text
目标：
      ┌──────
──────┘

实际：
         ╭────
─────────╯
```

可能和：

- P 偏低
- FF 偏低
- 动力响应慢
- 飞机惯量大

有关。

---

## 8.2 超调

```text
目标：
      ┌────────
──────┘

实际：
       /\
      /  \____
─────/
```

可能和：

- P 偏激进
- 阻尼不足
- D 不合适
- 结构弹性

有关。

---

## 8.3 振铃

```text
目标：────────────

实际：──/\/\/\────
```

目标已经稳定，实际还在来回摆。

这是明显需要关注的现象。

---

## 8.4 目标不动，实际自己乱跳

```text
RDes：────────────

R：   ─/\─/\/\──/\─
```

优先检查：

```text
机械振动
Gyro 噪声
Notch Filter
电机/桨
机架共振
```

不要第一反应就是改 P。

---

# 9. Pitch RATE

画：

```text
RATE.PDes
RATE.P
```

看法和 Roll 一样。

如果：

```text
Roll 很好
Pitch 很差
```

可以重点怀疑：

- Pitch 方向惯量更大
- 前后重心偏
- 前后结构刚度差
- Pitch PID 不合适
- 某方向存在共振

---

# 10. Yaw RATE

画：

```text
RATE.YDes
RATE.Y
```

如果：

```text
YDes = -300 deg/s
Y    = -100 deg/s
```

说明 Yaw 明显追不上。

不要直接判断：

```text
Yaw P 太小
```

还要看：

```text
RCOU
PIDY.Flags
电机余量
MOT_YAW_HEADROOM
```

---

# 11. 第四项：ATT

ATT 是姿态角。

常见：

```text
DesRoll
Roll
DesPitch
Pitch
DesYaw
Yaw
```

例如：

```text
ATT.DesRoll
ATT.Roll
```

表示：

```text
目标 Roll 角
实际 Roll 角
```

---

# 12. ATT 和 RATE 有什么区别

简单记：

```text
ATT  = 倾斜了多少度
RATE = 转得多快
```

例如：

```text
Roll = 20°
```

表示飞机当前已经横滚 20°。

而：

```text
RATE.R = 100°/s
```

表示飞机正在以每秒 100° 的速度横滚。

---

# 13. 为什么调 PID 先看 RATE

ArduPilot 姿态控制可以先简单理解成：

```text
目标姿态
   ↓
姿态外环
   ↓
目标角速度
   ↓
RATE PID
   ↓
Motor Mixer
   ↓
电机
```

所以：

```text
ATT.DesRoll
   ↓
RATE.RDes
   ↓
PID
   ↓
RATE.R
```

因此评价内环 PID 最直接的是：

```text
RATE.Des
vs
RATE.Actual
```

---

# 14. 第五项：PIDR / PIDP / PIDY

分别代表：

```text
PIDR = Roll
PIDP = Pitch
PIDY = Yaw
```

里面常见：

```text
Tar
Act
Err
P
I
D
FF
Dmod
SRate
Flags
```

---

# 15. PID 里面每个量是什么

## Tar

```text
Target
```

目标。

## Act

```text
Actual
```

实际。

## Err

```text
Err = Tar - Act
```

目标和实际之间的误差。

---

## P

比例项。

可以先理解成：

```text
现在差多少
立即纠正多少
```

P 太低可能：

```text
反应慢
```

P 太高可能：

```text
容易振荡
```

---

## I

积分项。

用于修正长期的小偏差，例如：

- 重心偏
- 电机推力差异
- 持续外力

如果 I 长时间很大，要检查为什么飞机一直需要补偿。

---

## D

微分项。

主要作用是增加阻尼、抑制快速变化。

但 D 对高频噪声非常敏感。

如果：

```text
机械振动大
 ↓
Gyro 抖
 ↓
D 抖
 ↓
电机也抖
```

所以机械问题没解决之前，不适合精调 D。

---

## FF

Feed Forward，前馈。

简单理解：

```text
还没出现很大误差
控制器就提前给动作
```

它用于提高跟踪性。

FF 不是用来治机械振动的。

---

## Flags

如果 PID 经常显示 LIMIT 类状态，说明：

```text
控制器想继续输出
但是电机 / Mixer 已经没有余量
```

这叫：

```text
饱和
```

---

# 16. 第六项：BAT

常看：

```text
Volt
Curr
CurrTot
```

## Volt

电池电压。

重点看：

```text
起飞前
悬停
大油门
```

如果一加油门电压掉很多，可能有：

- 电池内阻大
- 电池老化
- 电流太大
- 线材压降

## Curr

电流。

可以和：

```text
RCOU
VIBE
```

一起看。

有时候能发现：

```text
油门升高
 ↓
振动突然暴涨
```

---

# 17. 第七项：GPS

常看：

```text
Status
NSats
HDop
Spd
Alt
```

简单理解：

```text
NSats = 卫星数
HDop  = 水平定位精度指标，通常越小越好
```

如果 Loiter 异常，同时 GPS 状态也差，就不能只怪 PID。

---

# 18. 第八项：BARO

BARO 是气压计。

常看：

```text
Alt
Press
Temp
```

如果高度异常，可以对比：

```text
BARO.Alt
GPS.Alt
CTUN.Alt
```

---

# 19. 第九项：MAG

MAG 是磁罗盘。

如果日志中出现：

```text
EKF_YAW_RESET
Compass error
mag anomaly
```

就应该检查：

```text
MAG
```

以及磁罗盘安装、供电线、电机电流产生的磁干扰。

---

# 20. 第十项：EKF / XKF

EKF 是状态估计器。

它把：

```text
IMU
GPS
气压计
磁罗盘
```

融合成：

```text
姿态
速度
位置
航向
```

初学阶段不需要一上来研究全部 XKF 项。

先看：

```text
MSG
ERR
Events
```

有没有：

```text
EKF primary changed
EKF3 lane switch
EKF yaw reset
```

---

# 21. EKF lane switch 是什么

飞控可以同时运行多个 EKF lane。

如果某一路状态质量变差，可能：

```text
Lane 0
 ↓
Lane 1
```

日志会出现：

```text
EKF3 lane switch
EKF primary changed
```

如果它刚好发生在：

```text
VIBE 暴涨
Clip 增长
```

之后，就需要怀疑振动影响了状态估计。

---

# 22. MSG / ERR / Events 很重要

建议每次打开日志先勾：

```text
Events
Errors
MSG
```

先看整个过程：

- Armed
- 起飞
- 模式切换
- EKF 报错
- GPS 报错
- Compass 报错
- Land Complete
- Disarm

这样先知道“什么时候发生了什么”。

---

# 23. CTUN 是什么

可以先理解为：

```text
Copter Control Tuning
```

常用：

```text
Alt
DAlt
ThO
CRt
DCRt
```

其中：

```text
Alt  = 实际高度
DAlt = 目标高度
ThO  = 总体油门输出
```

---

# 24. 最推荐的基础分析顺序

## Step 1：Events / ERR / MSG

先确定：

```text
什么时候 Arm
什么时候起飞
什么飞行模式
有没有 EKF / GPS / Compass 错误
```

---

## Step 2：VIBE

画：

```text
VibeX
VibeY
VibeZ
Clip
```

如果多颗 IMU，就分别看。

---

## Step 3：RCOU

画：

```text
C1
C2
C3
C4
```

判断：

- 是否长期不平衡
- 是否触底
- 是否触顶
- 是否疯狂来回抽动

---

## Step 4：Roll RATE

```text
RATE.RDes
RATE.R
```

---

## Step 5：Pitch RATE

```text
RATE.PDes
RATE.P
```

---

## Step 6：Yaw RATE

```text
RATE.YDes
RATE.Y
```

---

## Step 7：ATT

```text
ATT.DesRoll
ATT.Roll
```

再看：

```text
ATT.DesPitch
ATT.Pitch
```

---

## Step 8：RATE 有问题再看 PID

Roll：

```text
PIDR.Tar
PIDR.Act
PIDR.Err
PIDR.P
PIDR.I
PIDR.D
PIDR.FF
PIDR.Flags
```

Pitch：

```text
PIDP.*
```

Yaw：

```text
PIDY.*
```

---

# 25. 常见问题模式

## 25.1 VIBE 高 + RATE Actual 很毛

```text
VIBE ↑
RATE 实际值高频乱跳
RCOU 高频抽动
```

优先检查：

```text
桨
电机
机臂
飞控减震
结构共振
```

---

## 25.2 目标动了，实际跟不上

可能：

```text
P偏低
FF偏低
动力响应慢
惯量大
```

---

## 25.3 实际严重超过目标

可能：

```text
P偏激进
阻尼不足
D不合适
结构弹性
```

---

## 25.4 目标不动，实际疯狂振荡

优先：

```text
机械 / Gyro / Filter
```

---

## 25.5 Yaw 一直追不上

先看：

```text
RCOU
PIDY.Flags
Motor saturation
MOT_YAW_HEADROOM
```

不要直接加 Yaw P。

---

## 25.6 一个电机长期比其他电机高

检查：

```text
重心
该电机/桨
电调
安装角
机架
```

---

# 26. 时间轴一定要放大

整个 1 分钟只能看趋势。

真正分析问题时，要把异常附近放大。

例如发现：

```text
17:08:23
```

附近出问题。

就只看：

```text
17:08:21 ～ 17:08:25
```

然后观察：

```text
谁先变化？
谁后变化？
```

---

# 27. “谁先变化”比单独看数值更重要

例如：

```text
VIBE 先暴涨
 ↓
RATE.Actual 开始抖
 ↓
PID.D 开始变大
 ↓
RCOU 开始抽动
```

说明机械振动很可能是前因。

如果：

```text
RCOU 先突然变化
 ↓
VIBE 再暴涨
```

可能是某个控制动作激发了结构共振。

---

# 28. 初学阶段最容易犯的错误

## 错误 1：VIBE 高就改 PID

正确：

```text
先解决机械
```

## 错误 2：Yaw 跟不上就加 Yaw P

正确：

```text
先看电机余量和 Flags
```

## 错误 3：只看 Max

Max 可能只是落地碰了一下。

更重要的是：

```text
是否持续
```

## 错误 4：一次改很多参数

建议：

```text
一次只解决一个问题
```

---

# 29. 推荐调参顺序

```text
机械检查
 ↓
VIBE / Clip
 ↓
FFT / Harmonic Notch
 ↓
Roll / Pitch RATE
 ↓
P / D
 ↓
I
 ↓
FF
 ↓
ATT 外环
 ↓
Yaw
 ↓
Loiter / Position
 ↓
AutoTune
```

---

# 30. 每次建议保存这几张图

```text
1. VIBE X/Y/Z + Clip
2. RCOU.C1~C4
3. RATE.RDes + RATE.R
4. RATE.PDes + RATE.P
5. RATE.YDes + RATE.Y
6. ATT.DesRoll + ATT.Roll
7. ATT.DesPitch + ATT.Pitch
8. PIDR Tar/Act/P/I/D/FF/Flags
9. PIDP Tar/Act/P/I/D/FF/Flags
```

---

# 31. 初学者快速检查表

```text
[ ] 有没有 Arm / Disarm
[ ] 飞行模式是什么
[ ] VIBE 是否明显偏高
[ ] Clip 是否为 0
[ ] 多颗 IMU 是否同时异常
[ ] RCOU 是否有电机长期触底
[ ] RCOU 是否有电机长期触顶
[ ] Roll RATE 是否跟目标
[ ] Pitch RATE 是否跟目标
[ ] Yaw RATE 是否跟目标
[ ] 有没有明显超调
[ ] 有没有明显振铃
[ ] PID Flags 是否长期 LIMIT
[ ] 有没有 EKF lane switch
[ ] 有没有 EKF yaw reset
[ ] GPS 有没有报错
[ ] Compass 有没有报错
[ ] 电池有没有明显掉压
```

---

# 32. 最后只记住这两张图

## 控制链

```text
ATT.Des
   ↓
姿态外环
   ↓
RATE.Des
   ↓
PID
   ↓
RCOU
   ↓
Motor
   ↓
飞机运动
   ↓
IMU / EKF
   ↓
反馈
```

## 分析顺序

```text
机械
 ↓
传感器
 ↓
状态估计
 ↓
控制器
 ↓
执行器
```

---

# 33. 一句话总结

看 ArduPilot Log，初学阶段先回答五个问题：

```text
1. 振不振？
2. 电机有没有控制余量？
3. RATE 目标和实际跟不跟？
4. PID 有没有一直撞限幅？
5. EKF 有没有报错？
```

按照：

```text
VIBE
→ RCOU
→ RATE
→ ATT
→ PID
→ EKF
```

这个顺序，就已经可以完成大多数基础飞行问题分析。

---

# 34. 下一步学习方向

看懂本文后，可以继续学：

1. FFT 频谱分析
2. Harmonic Notch
3. Gyro 原始数据
4. EKF Innovation
5. PID P/I/D/FF 定量分析
6. Motor thrust linearization
7. AutoTune 日志分析
8. Position / Velocity Controller

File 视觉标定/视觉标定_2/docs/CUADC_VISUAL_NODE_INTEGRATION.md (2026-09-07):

# 当前 CUADC 视觉节点集成约定

正式节点：

```text
~/cuadc_mission/src/cuadc_visual_drop_flight/scripts/drop_bucket_realsense_node.py
```

正式状态机接口必须保留：

```text
/perception/drop_buckets_body
geometry_msgs/PoseArray
frame_id = base_link
坐标 = FLU
```

标定扩展推荐提供：

```text
/cuadc/calib/annotated             sensor_msgs/Image
/cuadc/calib/color/image_raw       sensor_msgs/Image
/cuadc/calib/color/camera_info     sensor_msgs/CameraInfo
/vision_servo/targets_body         geometry_msgs/PoseArray, FRD
```

## 时间戳约定

必须继续使用相机 `wait_for_frames()` 后立即取得的同一个 `capture_stamp`：

```python
frames = pipeline.wait_for_frames(timeout_ms=5000)
capture_stamp = self.get_clock().now().to_msg()
```

图像、CameraInfo、正式 FLU 检测和 FRD 标定检测都应尽量使用同一采集时间戳。不要在推理完成后重新 `now()`。

## FLU -> FRD

```python
x_frd = x_flu
y_frd = -y_flu
z_frd = -z_flu
```

## 直接叠加模式

当前使用的参数约定：

```text
calibration_overlay_enabled
calibration_overlay_topic=/cuadc/calib/annotated
calibration_overlay_width
calibration_release_offsets_body_m
```

当前启动脚本见：

```text
bin/run_current_cuadc_visual_calibration.sh
```

## 相机独占

不要同时启动：

```text
drop_bucket_realsense_node.py
realsense2_camera
vision_provider_template（如果它自己打开相机）
```

D435i 只允许一个进程直接占用。

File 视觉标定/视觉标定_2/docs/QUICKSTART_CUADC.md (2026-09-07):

# CUADC 快速开始

## 1. 放置目录

建议：

```bash
mkdir -p ~/cuadc_mission/calibration
unzip cuadc_d435i_payload_calibration_2026_09_07.zip -d ~/cuadc_mission/calibration
cd ~/cuadc_mission/calibration/cuadc_d435i_payload_calibration_2026_09_07
chmod +x bin/*.sh tools/*.py
```

## 2. 推荐：当前正式视觉节点 + SSH 网页

终端 A：

```bash
./bin/run_current_cuadc_visual_calibration.sh ~/cuadc_mission
```

终端 B：

```bash
./bin/web_video_server.sh
```

Windows CMD：

```cmd
ssh -L 8080:127.0.0.1:8080 cuadc@NUC实际IP
```

浏览器：

```text
http://127.0.0.1:8080/stream?topic=/cuadc/calib/annotated&type=mjpeg
```

## 3. P1 采样

桶置于 P1 / SERVO9 中轴线正下方：

```bash
python3 tools/sample_payload_xy.py --payload 1 --true-x 0.026 --true-y -0.065 --duration 5
```

## 4. P2 采样

桶置于 P2 / SERVO10 中轴线正下方：

```bash
python3 tools/sample_payload_xy.py --payload 2 --true-x 0.0109 --true-y 0.072 --duration 5
```

## 5. 写入正式任务

```bash
python3 tools/apply_current_cuadc_calibration.py --workspace ~/cuadc_mission --dry-run
python3 tools/apply_current_cuadc_calibration.py --workspace ~/cuadc_mission
python3 tools/verify_current_workspace.py --workspace ~/cuadc_mission
```

然后重新编译正式包。

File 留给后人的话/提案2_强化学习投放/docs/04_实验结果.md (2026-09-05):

# 本次运行结果

日期：2026-09-05。以下数字来自本目录程序的实际本地运行。物理参数是演示假设，结果不能外推为实飞成功率。没有根据测试结果筛选模型；Q-learning 为训练种子 11 的最终 6000 回合模型，训练场景种子为 11000000–11005999。

## 25 cm 桶口，默认域随机化

四个策略分别测试 300 场，场景种子 80000000–80000299。有效命中半径为 9 cm。

| 策略 | 命中率 | 95% Wilson 区间 | 平均误差（已释放） | P90 误差（已释放） | 平均决策时间 |
|---|---:|---:|---:|---:|---:|
| 随机投放时机 | 16.3% | 12.6%–20.9% | 23.99 cm | 57.14 cm | 2.04 s |
| 悬停基线 | 92.7% | 89.1%–95.1% | 5.37 cm | 8.44 cm | 4.31 s |
| 弹道基线 | 66.3% | 60.8%–71.4% | 8.11 cm | 11.01 cm | 3.34 s |
| Q-learning | 83.7% | 79.1%–87.4% | 6.63 cm | 9.76 cm | 3.79 s |

此组所有策略释放率为 100%，无超时。Q-learning 较悬停基线平均提前约 0.52 s，但命中率低 9 个百分点，因此不能作为替换现有规则的依据。这里的悬停基线并非用户现有比赛控制器，实际旧方案需要另外对照。

## 压力场景和小桶外推

均使用同一个 25 cm 训练的 Q 模型，不为每个测试场景重训。每列的四种策略共享该列的 300 个场景种子。

| 策略 | 压力场景命中率 | 压力场景超时 | 20 cm 桶命中率 | 15 cm 桶命中率 |
|---|---:|---:|---:|---:|
| 随机 | 10.3% | 0 | 6.3% | 3.3% |
| 悬停 | 26.0% | 15 | 65.0% | 34.3% |
| 弹道 | 21.7% | 2 | 36.0% | 23.3% |
| Q-learning | 22.7% | 62 | 52.3% | 28.0% |

压力场景种子 81000000–81000299，15 cm 桶种子 83000000–83000299，20 cm 桶种子 84000000–84000299。压力场景 Q 的释放率为 79.3%，15 cm 为 89.7%，20 cm 为 98.3%。超时回合已计为未命中，没有通过剔除它们提高成功率。

Q 策略在未见过的离散状态选择等待，压力场景记录到 3421 次未见状态决策，这不是 3421 个独立回合。说明状态覆盖与分布外泛化不足；不能仅靠默认配置的小规模训练部署到更难场景。

## PPO 运行验证

独立 Python 3.12.4 虚拟环境，CPU 训练；请求 30000 步，SB3 按 rollout 批次实际执行 30208 步，未做超参数搜索。这是训练保存/加载与评估的运行验证，不是收敛证明。

同一批 100 场测试，种子 82000000–82000099：

| 策略 | 命中率 | 平均落点误差 | 平均决策时间 |
|---|---:|---:|---:|
| 悬停基线 | 92% | 5.59 cm | 4.36 s |
| 弹道基线 | 59% | 8.70 cm | 3.29 s |
| PPO 残差 | 70% | 7.14 cm | 7.17 s |

PPO 当前没有表现出对悬停基线的优势，决策更慢。它的测试种子与上面的 Q-learning 表不同，不能跨表用百分点直接比较 Q 和 PPO。若要正式比较，应使用统一测试场景并补足多个独立训练种子。

已验证版本：NumPy 2.5.2、Gymnasium 1.3.0、Stable-Baselines3 2.9.0、PyTorch 2.14.0+cpu。完整依赖快照见 `requirements-ppo-tested.txt`，模型和版本信息见 `examples/results/ppo_smoke.metadata.json`。

## 工程验证

- Python 3.14.5：标准库快速开始流程通过，18 项基础测试通过，1 项可选 Gym 检查按缺包跳过。
- Python 3.12.4 + PPO 依赖：19 项测试全部通过，包括 SB3 `check_env`。
- 验证了自由落体解析值、阻力退化、速度模型积分一致性、随机种子复现、无效观测阻止释放、单次释放、速度限幅、误差指标分母、四元数和投放口转换、过期与错帧拒绝、目标切换和锁存。
- 全程视觉丢失的示例持续到 12 s 超时，未释放。
- Edge 无界面浏览器实际打开 HTML 回放，无 JavaScript 错误；时间轴和播放可用；1280 px 桌面及 420 px 窄屏无水平溢出。
- 当前环境未进行 ROS 2/Gazebo 或实机联调。

原始逐场 CSV、完整 JSON、模型、训练记录和两种策略回放保存在 `examples/results/`，文件 SHA-256 见其中的 `manifest.json`。HTML 回放种子固定为 2026，保留 Q 的擦边失败与悬停的命中，便于比较。

## 如何解释结果

此草案已经实现“训练环境 → 策略学习 → 保存模型 → 独立场景评估 → 可视化复查”的完整软件闭环。后续最有价值的工作是结合现有日志校正模型、统一新旧控制器的动作接口，并验证真正的实机误差来源。当前数据支持继续开展实验，不支持宣称强化学习已优于稳定规则投放。

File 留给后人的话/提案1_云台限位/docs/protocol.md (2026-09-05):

# NUC—STM32 串口协议

物理层：115200 bit/s，8 数据位，无校验，1 停止位。命令是大写 ASCII，以 `\n` 或 `\r\n` 结束。

## 命令

| 命令 | 作用 | 限制 |
|---|---|---|
| `STATUS?` | 立即返回一帧遥测 | 无 |
| `ARM` | 进入稳定闭环 | 仅 `READY` |
| `DISARM` | 停止更新控制器并保持当前 PWM | 无 |
| `ZERO` | 把当前静止姿态定义为 0° | 仅 `READY`、近似 1 g、角速度小 |
| `SET,r,p` | 设置 Roll/Pitch 目标角（度） | 固件限幅为 Roll ±20°、Pitch ±30° |
| `GAIN,R,ka,kr,mr,ms` | 设置 Roll 的四个参数 | 仅 `READY` |
| `GAIN,P,ka,kr,mr,ms` | 设置 Pitch 的四个参数 | 仅 `READY` |

增益字段依次为姿态比例 `ka`、角速度比例 `kr`、最大目标角速度 `mr`、最大舵机变化率 `ms`。

## 响应

- 成功：`ACK,<命令>`
- 失败：`ERR,<原因>`
- 提示：`INFO,<文本>`
- 遥测：

  ```text
  TEL,state,roll,pitch,roll_rate,pitch_rate,accel_norm,servo_roll,servo_pitch,imu_failures
  ```

角度单位为度，角速度单位为度/秒，加速度模长单位为 g。固件主动以 20 Hz 发送遥测，`STATUS?` 也会触发一帧。

示例：

```text
> STATUS?
< TEL,READY,0.231,-0.418,0.031,-0.015,1.002,0.00,0.00,0
> ZERO
< ACK,ZERO
> ARM
< ACK,ARM
```

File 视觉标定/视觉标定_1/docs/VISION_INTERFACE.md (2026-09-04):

# Vision Provider Interface

## 1. 目标

视觉提供者（Vision Provider）与准星/标定逻辑之间只通过标准 ROS 2 消息连接。视觉提供者可以是任何算法，只要最终把目标三维点转换到 FCU body FRD 并发布。

默认：

- topic: `/vision_servo/targets_body`
- type: `geometry_msgs/msg/PoseArray`
- frame: `fcu_body_frd`

## 2. PoseArray 字段

| 字段 | 含义 | 必需 |
|---|---|---:|
| `header.stamp` | 原始图像采集时间 | 是 |
| `header.frame_id` | `fcu_body_frd` | 是 |
| `pose.position.x` | 目标参考点，FRD 前向，m | 是 |
| `pose.position.y` | 目标参考点，FRD 右向，m | 是 |
| `pose.position.z` | 目标参考点，FRD 下向，m | 是 |
| `pose.orientation.x` | 目标尺度/直径，m；未知可 0 | 否 |
| `pose.orientation.y` | 置信度 `[0,1]`；未知填 1 | 建议 |
| `pose.orientation.z` | 视觉节点自定义深度诊断值 | 否 |
| `pose.orientation.w` | 契约版本哨兵 `1.0` | 是 |

`orientation` **不是四元数**，只借用 `PoseArray` 的四个标量避免引入自定义消息包。

## 3. 空检测帧

每处理一帧有效图像，都建议发布一次 `PoseArray`。没有目标时：

```text
poses = []
```

仍应保留正确的 `header.stamp` 和 `header.frame_id`。这样下游可以区分“视觉节点活着但没目标”与“视觉节点已经停止”。

## 4. 时间戳

`header.stamp` 应对应产生这些检测结果的**图像采集时间**，不要在推理结束时重新取 `now()`。如果后续把同一话题用于飞行控制，这一点关系到机体运动补偿和历史里程计插值。

## 5. 坐标变换

若算法先得到相机光学坐标 `p_camera`，配置定义：

```text
p_body_frd = R_body_camera @ p_camera + t_body_camera
```

其中：

- `R_body_camera` 为 `camera.rotation_camera_to_frd`；
- `t_body_camera` 为 `camera.translation_frd_m`；
- 相机光学坐标通常为 `+X` 图像右、`+Y` 图像下、`+Z` 光轴前；
- body FRD 为 `+X` 前、`+Y` 右、`+Z` 下。

仓库中的 `projection.py` 提供了对应函数。

## 6. 对准平面

视觉发布的是“目标参考点”。准星节点用：

```text
alignment_plane_z = target_reference_z - target.height_m
```

例如：

- 视觉 3D 点是桶底/地面中心，桶高 0.30 m：`target.height_m = 0.30`；
- 视觉 3D 点已经在桶口平面：`target.height_m = 0.0`。

Payload 准星使用 `[payload_x, payload_y, alignment_plane_z]`，因此准星与目标 `x/y` 无关，不会自动跟着目标跑。

## 7. 图像接口

独立准星节点还需要：

- `sensor_msgs/msg/Image`
- `sensor_msgs/msg/CameraInfo`

二者话题由 `config/aircraft.yaml` 指定。相机内参直接来自 `CameraInfo.K`；不把焦距/主点写死在代码里。

## 8. 接入已有视觉节点

已有节点只需增加一个发布器，把内部结果转换成上述 `PoseArray`。不需要复制本仓库的模板，也不需要修改 `alignment_viewer`。

接入后运行：

```bash
./bin/check_vision_contract.sh
```

检查时间戳、frame、有限数值、置信度和版本哨兵。

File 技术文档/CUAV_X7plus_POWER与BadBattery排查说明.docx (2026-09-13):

CUAV X7+ POWER 接口与 Bad Battery 排查说明

适用于 ArduPilot / Mission Planner 场景

先记住这一条

CAN PMU Lite / CAN PMU SE → POWER C → DroneCAN；模拟 HV_PM → POWER A → ADC。接口与监测协议不匹配，是 X7+ 出现 Battery Not Healthy / Bad Battery 时应优先排查的问题。

1. POWER A、POWER C 与 CAN1 的区别

接口 | 主要用途 | 电量检测方式 | 典型连接
POWER A | 飞控供电 + 电压/电流检测 | 模拟 ADC | HV_PM、普通模拟电源模块
CAN1 | 普通 CAN 总线通信 | 不是传统电源检测口 | CAN GPS、CAN 外设
POWER C | 飞控供电 + 数字电量检测 | DroneCAN / CAN | CAN PMU Lite、CAN PMU SE

- POWER A：传统模拟电源模块接口，电压/电流通过 ADC 采样。
- POWER C：X7+ 原配 CAN PMU 的推荐接口，电压/电流通过 DroneCAN 数字通信。
- CAN1：普通 CAN 接口，不应把它理解为 “POWER B”。

2. Bad Battery 与 Battery Not Healthy 的区别

- Bad Battery：通常是警告信息，可能由电压/电流参数异常、飞行中电压下降明显等引起。
- Battery Not Healthy：通常出现在 PreArm 预检中，应重点检查电池监测参数、CAN 通信或电流计连接。
- 如果关闭了 Arming Check 中的电池预检，原本的 Battery1 Not Healthy 可能只表现为 Bad Battery；关闭预检并没有解决根因。

3. X7+ 出现报错时的推荐排查顺序

步骤 1｜先确认电流计类型和物理接口

- CAN PMU Lite / CAN PMU SE：接 POWER C。不要把 CAN PMU 当成模拟 PM 接到 POWER A / Power 1。
- HV_PM 等模拟电池监测器：接 POWER A。

步骤 2｜CAN PMU（POWER C）检查参数

BATT_MONITOR = 8

CAN_P1_DRIVER = 1

CAN_P2_DRIVER = 1

X7 系列原配 CAN PMU 通常已配置为即插即用；如果此前在 Mission Planner 的“电池监视器”页面改过设置，应回到“全部参数表”核对以上参数。

步骤 3｜模拟 HV_PM（POWER A）检查参数

BATT_MONITOR = 4

BATT_VOLT_MULT = 18

BATT_VOLT_PIN = 16

BATT_CURR_PIN = 17

BATT_AMP_PERVLT = 24

说明：部分 CUAV 页面/附件中写作 “BATT_V0LT_PIN”（数字 0），ArduPilot 实际参数名为 BATT_VOLT_PIN（字母 O）。

步骤 4｜只有电压、没有电流

- 模拟 HV_PM：重点检查 BATT_CURR_PIN。如果被设为 -1，电流采样会被禁用；X7 系列模拟监测通常应为 17。
- CAN PMU：不要用模拟针脚参数去“修”CAN 电流计，应先确认 POWER C 接线、CAN 驱动和 DroneCAN 电池监测是否正常。

步骤 5｜电压校准

- 模拟 HV_PM：参数设置完成后，可用万用表测量电池真实电压，再在 Mission Planner 中校准电压读数。
- CAN PMU（POWER C）：通常不需要按模拟电流计的方法进行电压倍率校准。

快速判断

X7+ 原配 CAN PMU + POWER C：优先检查 BATT_MONITOR=8 与 CAN 驱动；
HV_PM + POWER A：优先检查 BATT_MONITOR=4、BATT_VOLT_PIN=16、BATT_CURR_PIN=17。
不要用关闭 Battery Arming Check 代替故障排查。

4. 供电注意事项

- 6S、12S 等动力电池不能直接接入飞控 POWER A / POWER C 的低压供电脚，必须经过对应 PMU / 电源模块。
- 在排查 Bad Battery 前，先确认飞控显示的电池电压与万用表实测值是否基本一致；若差异明显，再进一步检查参数或传感链路。

参考依据

• CUAV X7+ ArduPilot 用户手册 / 快速布线指南（Battery Monitoring / Power）

• 用户提供：《如何解决 bad battery 报错》

CUAV X7+ 电源与电池监测速查

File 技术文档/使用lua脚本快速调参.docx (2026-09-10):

使用lua脚本，快速对无人机的角速率环进行调参

一、lua调参脚本的下载

https://www.wwzhyun.cn/docs/pid-apm-pid-3-lua-pd-bbe959d2a5

(https://www.wwzhyun.cn/docs/pid-apm-pid-3-lua-pd-bbe959d2a5)

进入网址后下载解压，.lua格式的文件便是脚本文件，文件快速调参脚本的名称写着是：VTOL-quicktune.lua

二、lua调参脚本-具体配置

1.TF卡准备

将飞控的TF卡或SD卡（依飞控型号定）进行格式化 (电脑默认格式化方式即可)

2.使能脚本功能

1）飞控上电，MP地面站搜索参数：SCR_ENABLE ，设为1，使能lua脚本功能。

2）给飞控断电，将格式化后的TF卡插入到飞控的TF卡槽中。

3）重新给飞控上电，并连接MP地面站

3.通过MAVftp上传脚本文件到TF卡中

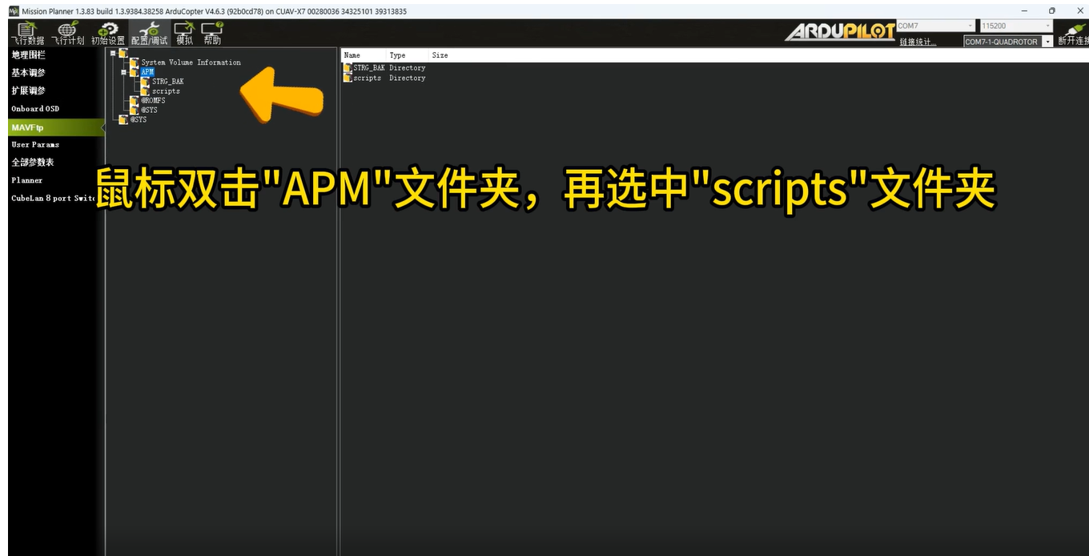
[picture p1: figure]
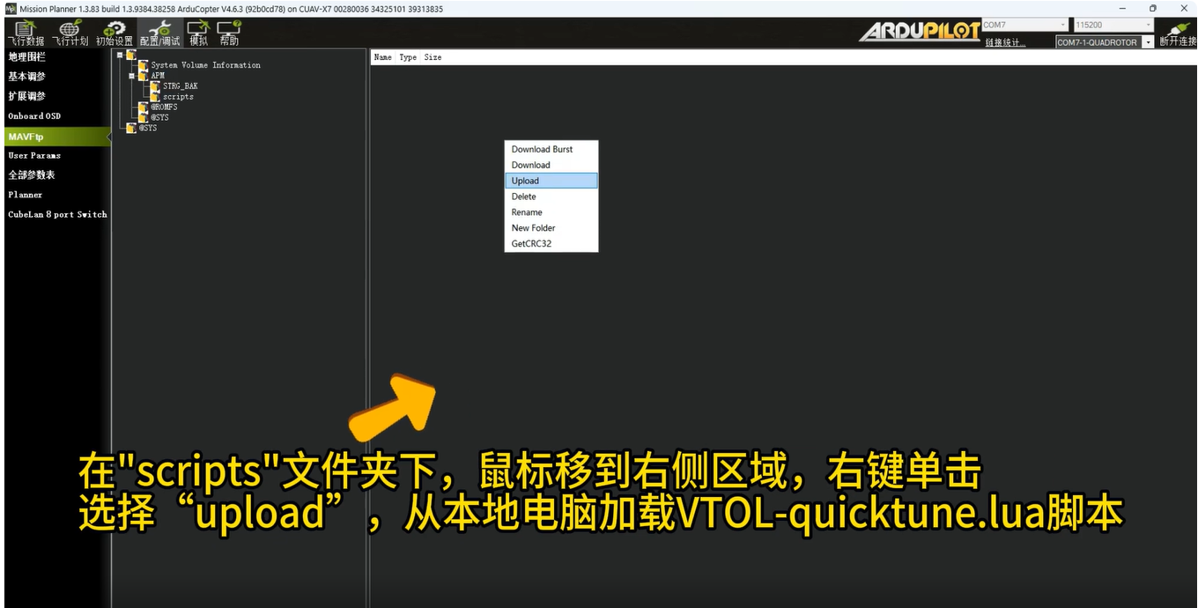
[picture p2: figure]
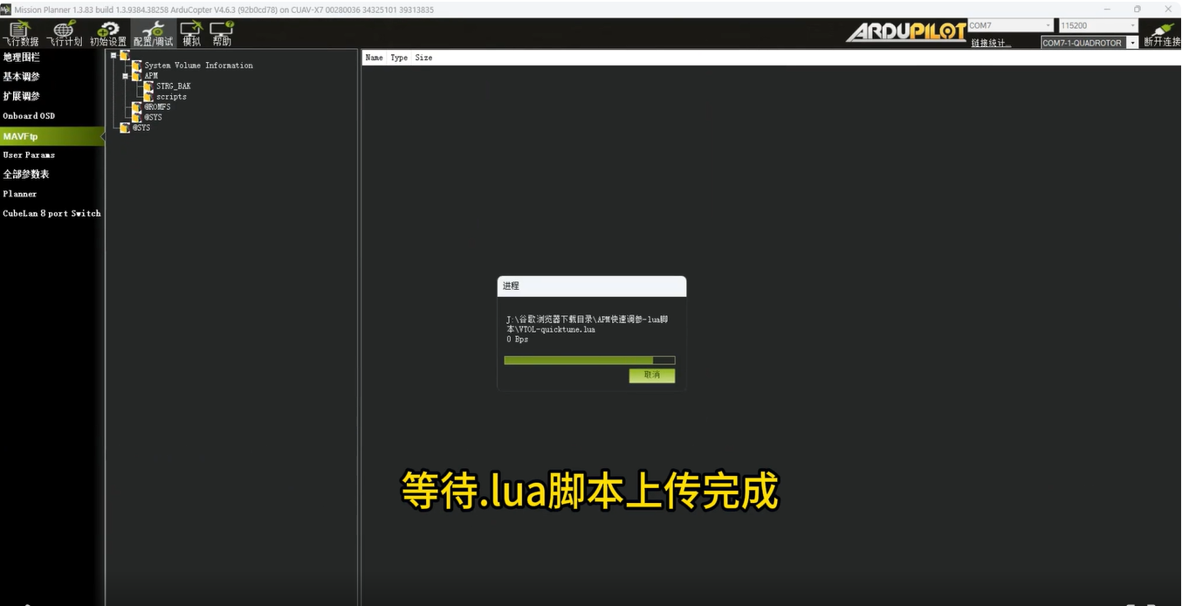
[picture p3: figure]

上传完成之后，重启飞控

注：如果发现没有scripts文件夹，用户可将鼠标放在右侧空白区域，右键新建New Floder，并命名为scripts文件夹即可！

4.使用快速调参重启飞控后，通过MP地面站，刷新参数；搜索参数 QUIK_ENABLE ，将其设为1，使能快速调参！

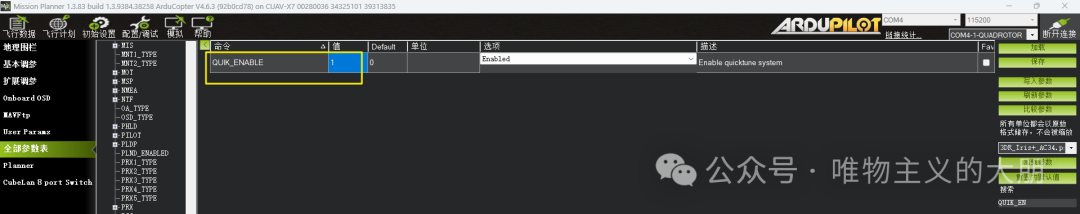
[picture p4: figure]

5.选择遥控器上的一个3挡开关

在遥控器上找一个3挡位波动开关的通道。

这个3挡开关通道的中间挡位表示：自动调参开始！

调参完成后，打到低PWM值的档位，表示放弃保存调参后的参数。

调参完成后，打到高PWM值的挡位，保存调参后的参数据！

这里我们假设用遥控器的通道7。将通道7的功能设置为300(这个值是脚本默认写死的)

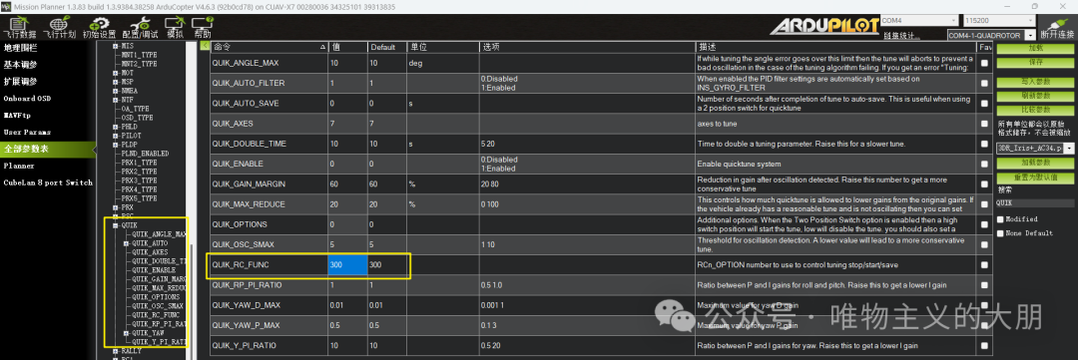
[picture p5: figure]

由于前面我们假设，遥控器通道7这个3挡位开关，作为调参保存与不保存的通道，因此我们需要将RC7_OPTION = 300。

上述设置完成后，在“扩展调参”页面中，可以看到7通道的功能已被修改！

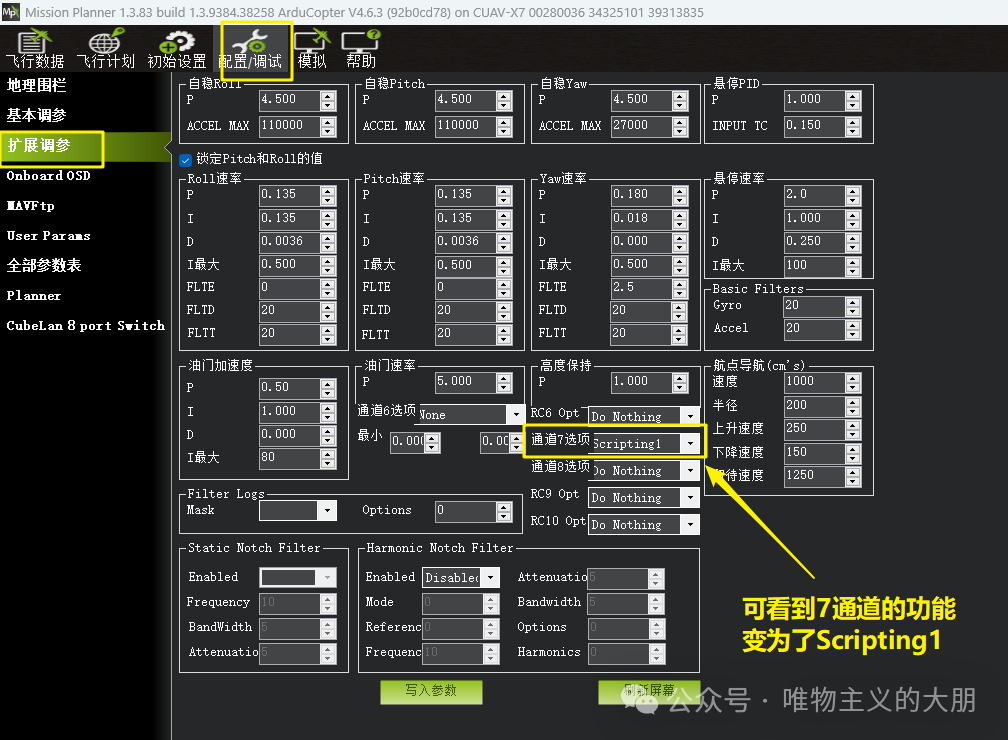
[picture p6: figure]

重启飞控，上电后，地面站会提示“多旋翼快速调参已加载”

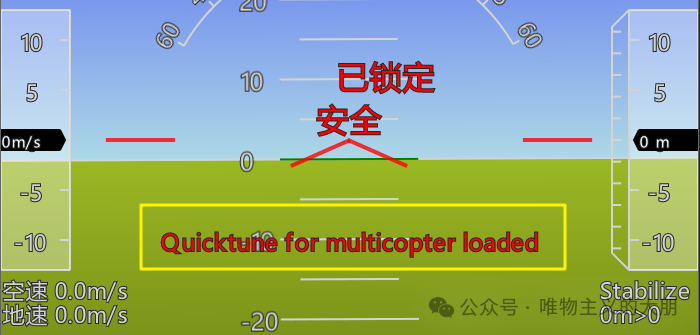
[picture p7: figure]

6.开始脚本自动调参

1）将遥控器设置的7通道打到中间挡位，无人机处于地面时未解锁时，地面站的消息栏会一直提示“必须起飞后才能进行调参”，如下图所示：

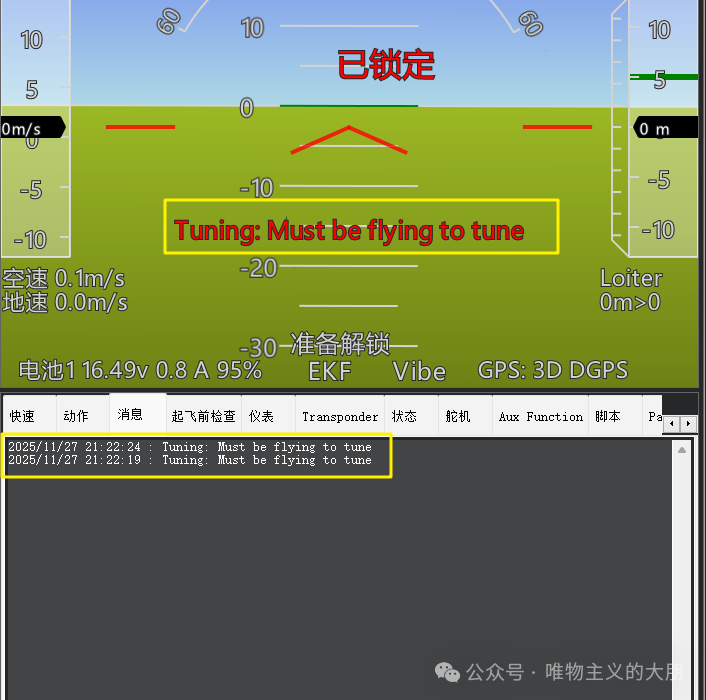
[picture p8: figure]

2）此时，我们将无人机解锁起飞到距离地面3-5m的高度，并切换到Loiter模式后(也可以直接以Loiter模式起飞)，飞控便开始自动调参！

地面站会显示“Tuning：starting tune” (调参开始)

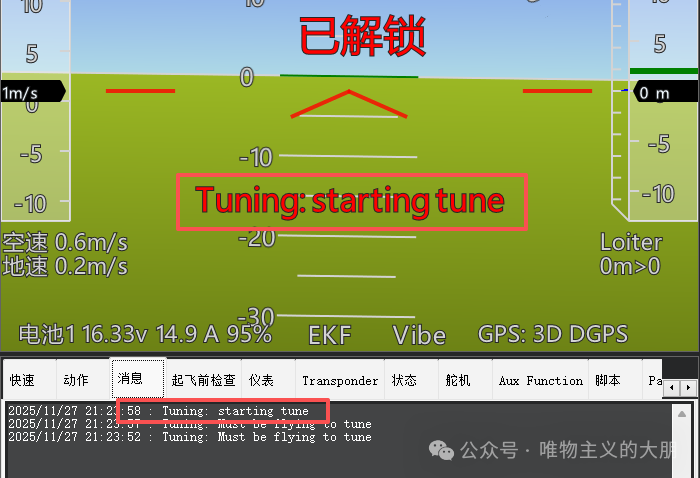
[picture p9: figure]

4）当地面站提示："Tuning DONE"(调参完成)

我们将3挡开关打到高PWM值挡位，会提示“save”(保存参数)！

如果将3档开关打到低PWM值挡位，会提示“reserve” (放弃保存参数)！

5） 保存参数后，再到地面站“配置/调试” ->“扩展调参”，我们就可以看到快速调参之后的PID参数，我们点击“写入参数”。

6）所有调参结束后，我们需要关闭快速调参功能、关闭脚本功能、关闭7通道功能，在MP地面站中分别将以下参数设置为0！QUIK_ENABLE = 0SCR_ENABLE = 0RC7_OPTION = 0然后重启飞控！至此完成最内环角速率环节的PID参数的快速调整！

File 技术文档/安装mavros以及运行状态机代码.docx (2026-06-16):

以下配置针对ros2 humble，ubuntu22.04系统（ros2 humble通过fishros一键安装即可，请务必也在无conda等虚拟环境的情况下安装ros2）

以下教程建议全程禁用 conda 及其他虚拟环境.特别提醒：即使是conda安装后自动启动的base环境也不可以，使用conda deactivate退出base环境。

请先观看《基于ardupilot的gazebo仿真环境配置教程.docx》，配置好ardupilot，gazebo，ardupilot_gazebo插件以后再看此教程

0．退出虚拟环境

bash

conda deactivate

conda config --set auto_activate false

使用命令行conda config --set auto_activate false配置 conda 不自动激活 base，这样不用每次开新终端时都执行conda deactivate。建议：不仅配置环境的时候不要使用虚拟环境，运行仿真的时候也不要使用虚拟环境。（特别是conda会对ros2 gazebo等这些硬件相关的工具的环境变量造成巨大的篡改，导致难以解释和解决的错误；即使是venv也很费事，为了简单就禁用虚拟环境吧）

1. 安装mavros并下载地理信息数据

bash

sudo apt install ros-humble-mavros ros-humble-mavros-extras

sudo /opt/ros/humble/lib/mavros/install_geographiclib_datasets.sh

2. 创建状态机代码的ROS2工作环境

bash

# 创建工作空间

mkdir -p ~/ws_offboard/src

cd ~/ws_offboard/src

# 创建功能包（包含依赖 mavros_msgs, geometry_msgs, rclcpp）

ros2 pkg create offboard_control --build-type ament_cmake --dependencies rclcpp geometry_msgs mavros_msgs

2.1编写状态机代码

在~/ws_offboard/src/offboard_control/src/文件夹下创建一个cpp代码，名字为offb_node.cpp，以下是代码内容：

cpp

/**

* @file offb_node.cpp

* @brief Pure takeoff solution 鈥?no setpoint during takeoff to avoid conflict.

*/

#include <rclcpp/rclcpp.hpp>

#include <geometry_msgs/msg/pose_stamped.hpp>

#include <mavros_msgs/msg/state.hpp>

#include <mavros_msgs/srv/command_bool.hpp>

#include <mavros_msgs/srv/set_mode.hpp>

#include <mavros_msgs/srv/command_tol.hpp>

#include <nav_msgs/msg/odometry.hpp>

#include <chrono>

#include <memory>

#include <string>

#include <vector>

#include <cmath>

using namespace std::chrono_literals;

enum class MissionState {

WAITING_FCU,

SETTING_GUIDED,

ARMING,

TAKEOFF,

FLYING_WAYPOINTS,

LANDING,

DONE

};

class OffboardControl : public rclcpp::Node {

public:

OffboardControl() : Node("offb_node") {

// QoS compatible with mavros

rclcpp::QoS odom_qos = rclcpp::QoS(rclcpp::KeepLast(10)).best_effort();

rclcpp::QoS state_qos = rclcpp::QoS(rclcpp::KeepLast(10)).best_effort();

state_sub_ = this->create_subscription<mavros_msgs::msg::State>(

"/mavros/state", state_qos,

std::bind(&OffboardControl::state_cb, this, std::placeholders::_1));

local_pos_sub_ = this->create_subscription<nav_msgs::msg::Odometry>(

"/mavros/local_position/odom", odom_qos,

std::bind(&OffboardControl::local_pos_cb, this, std::placeholders::_1));

setpoint_pub_ = this->create_publisher<geometry_msgs::msg::PoseStamped>(

"/mavros/setpoint_position/local", rclcpp::QoS(10).reliable());

arming_cli_ = this->create_client<mavros_msgs::srv::CommandBool>("/mavros/cmd/arming");

set_mode_cli_ = this->create_client<mavros_msgs::srv::SetMode>("/mavros/set_mode");

takeoff_cli_ = this->create_client<mavros_msgs::srv::CommandTOL>("/mavros/cmd/takeoff");

land_cli_ = this->create_client<mavros_msgs::srv::CommandTOL>("/mavros/cmd/land");

timer_ = this->create_wall_timer(50ms, std::bind(&OffboardControl::control_loop, this));

current_target_ = {0.0, 0.0, 0.0};

publish_setpoint_enabled_ = true;

RCLCPP_INFO(this->get_logger(), "Offboard node started (pure takeoff mode)");

}

private:

void state_cb(const mavros_msgs::msg::State::SharedPtr msg) {

current_state_ = *msg;

}

void local_pos_cb(const nav_msgs::msg::Odometry::SharedPtr msg) {

current_altitude_ = msg->pose.pose.position.z;

current_position_.x = msg->pose.pose.position.x;

current_position_.y = msg->pose.pose.position.y;

}

void publish_setpoint(double x, double y, double z) {

if (!publish_setpoint_enabled_) return;

geometry_msgs::msg::PoseStamped sp;

sp.header.stamp = this->now();

sp.header.frame_id = "map";

sp.pose.position.x = x;

sp.pose.position.y = y;

sp.pose.position.z = z;

sp.pose.orientation.w = 1.0;

setpoint_pub_->publish(sp);

current_target_ = {x, y, z};

}

void call_set_mode(const std::string& mode) {

if (!set_mode_cli_->service_is_ready()) return;

auto req = std::make_shared<mavros_msgs::srv::SetMode::Request>();

req->custom_mode = mode;

auto future = set_mode_cli_->async_send_request(req);

pending_set_mode_future_ = future.future.share();

RCLCPP_INFO(get_logger(), "Requested mode: %s", mode.c_str());

}

void call_arm(bool arm) {

if (!arming_cli_->service_is_ready()) return;

auto req = std::make_shared<mavros_msgs::srv::CommandBool::Request>();

req->value = arm;

auto future = arming_cli_->async_send_request(req);

pending_arm_future_ = future.future.share();

RCLCPP_INFO(get_logger(), "Requested arming: %s", arm ? "true" : "false");

}

void call_takeoff(float alt) {

if (!takeoff_cli_->service_is_ready()) {

RCLCPP_WARN(get_logger(), "Takeoff service not ready");

return;

}

auto req = std::make_shared<mavros_msgs::srv::CommandTOL::Request>();

req->altitude = alt;

auto future = takeoff_cli_->async_send_request(req);

pending_takeoff_future_ = future.future.share();

RCLCPP_INFO(get_logger(), "Takeoff command sent to %.1f m", alt);

}

void call_land() {

if (!land_cli_->service_is_ready()) return;

auto req = std::make_shared<mavros_msgs::srv::CommandTOL::Request>();

land_cli_->async_send_request(req);

RCLCPP_INFO(get_logger(), "Land command sent");

}

void control_loop() {

if (publish_setpoint_enabled_) {

publish_setpoint(current_target_.x, current_target_.y, current_target_.z);

}

if (pending_set_mode_future_.valid() &&

pending_set_mode_future_.wait_for(0s) == std::future_status::ready) {

auto result = pending_set_mode_future_.get();

if (result->mode_sent) {

RCLCPP_INFO(get_logger(), "GUIDED mode confirmed");

guided_mode_confirmed_ = true;

} else {

RCLCPP_WARN(get_logger(), "Set mode failed, will retry");

}

pending_set_mode_future_ = {};

}

if (pending_arm_future_.valid() &&

pending_arm_future_.wait_for(0s) == std::future_status::ready) {

auto result = pending_arm_future_.get();

if (result->success) {

RCLCPP_INFO(get_logger(), "Arming confirmed");

armed_confirmed_ = true;

current_target_ = {0.0, 0.0, TAKEOFF_ALT};

RCLCPP_INFO(get_logger(), "Setpoint target set to (0,0,%.1f) (will be published after takeoff)", TAKEOFF_ALT);

} else {

RCLCPP_WARN(get_logger(), "Arming failed, will retry");

}

pending_arm_future_ = {};

}

if (pending_takeoff_future_.valid() &&

pending_takeoff_future_.wait_for(0s) == std::future_status::ready) {

auto result = pending_takeoff_future_.get();

if (result->success) {

RCLCPP_INFO(get_logger(), "Takeoff command accepted by FCU");

} else {

RCLCPP_WARN(get_logger(), "Takeoff command rejected");

}

pending_takeoff_future_ = {};

}

switch (mission_state_) {

case MissionState::WAITING_FCU:

if (current_state_.connected) {

RCLCPP_INFO(get_logger(), "FCU connected");

mission_state_ = MissionState::SETTING_GUIDED;

}

break;

case MissionState::SETTING_GUIDED:

if (current_state_.mode == "GUIDED") {

guided_mode_confirmed_ = true;

}

if (!guided_mode_confirmed_ && !pending_set_mode_future_.valid()) {

call_set_mode("GUIDED");

} else if (guided_mode_confirmed_) {

mission_state_ = MissionState::ARMING;

}

break;

case MissionState::ARMING:

if (current_state_.armed) {

armed_confirmed_ = true;

}

if (!armed_confirmed_ && !pending_arm_future_.valid()) {

call_arm(true);

} else if (armed_confirmed_) {

mission_state_ = MissionState::TAKEOFF;

}

break;

case MissionState::TAKEOFF: {

static bool takeoff_sent = false;

publish_setpoint_enabled_ = false;

if (!takeoff_sent) {

call_takeoff(TAKEOFF_ALT);

takeoff_sent = true;

takeoff_start_time_ = this->now();

}

if (current_altitude_ >= TAKEOFF_ALT * 0.95) {

RCLCPP_INFO(get_logger(), "Takeoff reached target altitude (%.2f m)", current_altitude_);

publish_setpoint_enabled_ = true;

mission_state_ = MissionState::FLYING_WAYPOINTS;

takeoff_sent = false;

waypoint_index_ = 0;

last_waypoint_time_ = this->now();

current_target_ = {0.0, 0.0, TAKEOFF_ALT};

} else if ((this->now() - takeoff_start_time_).seconds() > 60.0) {

RCLCPP_WARN(get_logger(), "Takeoff timeout (60s), forcing to waypoints");

publish_setpoint_enabled_ = true;

mission_state_ = MissionState::FLYING_WAYPOINTS;

takeoff_sent = false;

}

break;

}

case MissionState::FLYING_WAYPOINTS: {

const std::vector<std::array<double, 2>> waypoints = {

{0.0, 0.0}, {5.0, 0.0}, {5.0, 5.0}, {0.0, 5.0}, {0.0, 0.0}

};

double z = TAKEOFF_ALT;

if (waypoint_index_ < waypoints.size()) {

double target_x = waypoints[waypoint_index_][0];

double target_y = waypoints[waypoint_index_][1];

current_target_ = {target_x, target_y, z};

double dx = current_position_.x - target_x;

double dy = current_position_.y - target_y;

double dist = std::hypot(dx, dy);

if (dist < 0.5) {

if ((this->now() - last_waypoint_time_).seconds() > 2.0) {

RCLCPP_INFO(get_logger(), "Waypoint %zu reached", waypoint_index_+1);

waypoint_index_++;

last_waypoint_time_ = this->now();

}

} else {

last_waypoint_time_ = this->now();

}

} else {

mission_state_ = MissionState::LANDING;

}

break;

}

case MissionState::LANDING: {

static bool land_sent = false;

if (!land_sent) {

call_land();

land_sent = true;

current_target_ = {current_position_.x, current_position_.y, 0.0};

}

if (current_altitude_ < 0.2) {

RCLCPP_INFO(get_logger(), "Landed, mission complete");

mission_state_ = MissionState::DONE;

}

break;

}

case MissionState::DONE:

RCLCPP_INFO(get_logger(), "Shutting down");

rclcpp::shutdown();

break;

}

}

rclcpp::Subscription<mavros_msgs::msg::State>::SharedPtr state_sub_;

rclcpp::Subscription<nav_msgs::msg::Odometry>::SharedPtr local_pos_sub_;

rclcpp::Publisher<geometry_msgs::msg::PoseStamped>::SharedPtr setpoint_pub_;

rclcpp::Client<mavros_msgs::srv::CommandBool>::SharedPtr arming_cli_;

rclcpp::Client<mavros_msgs::srv::SetMode>::SharedPtr set_mode_cli_;

rclcpp::Client<mavros_msgs::srv::CommandTOL>::SharedPtr takeoff_cli_;

rclcpp::Client<mavros_msgs::srv::CommandTOL>::SharedPtr land_cli_;

rclcpp::TimerBase::SharedPtr timer_;

mavros_msgs::msg::State current_state_;

double current_altitude_ = 0.0;

struct { double x=0, y=0; } current_position_;

MissionState mission_state_ = MissionState::WAITING_FCU;

struct Target { double x=0, y=0, z=0; } current_target_;

bool publish_setpoint_enabled_ = true;

const double TAKEOFF_ALT = 2.0;

size_t waypoint_index_ = 0;

rclcpp::Time last_waypoint_time_;

rclcpp::Time takeoff_start_time_;

std::shared_future<std::shared_ptr<mavros_msgs::srv::SetMode::Response>> pending_set_mode_future_;

std::shared_future<std::shared_ptr<mavros_msgs::srv::CommandBool::Response>> pending_arm_future_;

std::shared_future<std::shared_ptr<mavros_msgs::srv::CommandTOL::Response>> pending_takeoff_future_;

bool guided_mode_confirmed_ = false;

bool armed_confirmed_ = false;

};

int main(int argc, char **argv) {

rclcpp::init(argc, argv);

auto node = std::make_shared<OffboardControl>();

rclcpp::spin(node);

rclcpp::shutdown();

return 0;

}

以上状态机代码执行的效果是：无人机先起飞，再在（与地面平行的）平面内飞了一个矩形，最后降落回起飞点。

因为我的环境有两个缺陷：执行mode guided以后有可能不进入GUIDED模式；执行arm throttle以后有可能解锁失败，即使成功也有可能快速又锁上。状态机代码针对以上两点做了相应的处理：多次执行mode guided直到进入GUIDED模式，多次执行arm throttle，只要检测到解锁成功立马执行takeoff指令（防止重新被锁上）。

希望有人可以改进我的环境配置方法，进而解决这两个缺陷

2.2修改编译配置相关文件

编辑~/ws_offboard/src/offboard_control下的 CMakeLists.txt和 package.xml

CMakeLists.txt

cmake_minimum_required(VERSION 3.8)

project(offboard_control)

if(CMAKE_COMPILER_IS_GNUCXX OR CMAKE_CXX_COMPILER_ID MATCHES "Clang")

add_compile_options(-Wall -Wextra -Wpedantic)

endif()

# find dependencies

find_package(ament_cmake REQUIRED)

find_package(rclcpp REQUIRED)

find_package(geometry_msgs REQUIRED)

find_package(mavros_msgs REQUIRED)

find_package(nav_msgs REQUIRED)

if(BUILD_TESTING)

find_package(ament_lint_auto REQUIRED)

# the following line skips the linter which checks for copyrights

# comment the line when a copyright and license is added to all source files

set(ament_cmake_copyright_FOUND TRUE)

# the following line skips cpplint (only works in a git repo)

# comment the line when this package is in a git repo and when

# a copyright and license is added to all source files

set(ament_cmake_cpplint_FOUND TRUE)

ament_lint_auto_find_test_dependencies()

endif()

ament_package()

add_executable(offb_node src/offb_node.cpp)

target_include_directories(offb_node PUBLIC

$<BUILD_INTERFACE:${CMAKE_CURRENT_SOURCE_DIR}/include>

$<INSTALL_INTERFACE:include/offboard_control>)

target_compile_features(offb_node PUBLIC c_std_99 cxx_std_17)

ament_target_dependencies(offb_node rclcpp geometry_msgs mavros_msgs nav_msgs )

install(TARGETS offb_node

DESTINATION lib/${PROJECT_NAME})

package.xml

<?xml version="1.0"?>

<?xml-model href="http://download.ros.org/schema/package_format3.xsd" schematypens="http://www.w3.org/2001/XMLSchema"?>

<package format="3">

<name>offboard_control</name>

<version>0.0.0</version>

<description>TODO: Package description</description>

<maintainer email="zxx@todo.todo">zxx</maintainer>

<license>TODO: License declaration</license>

<buildtool_depend>ament_cmake</buildtool_depend>

<depend>rclcpp</depend>

<depend>geometry_msgs</depend>

<depend>mavros_msgs</depend>

<depend>nav_msgs</depend>

<test_depend>ament_lint_auto</test_depend>

<test_depend>ament_lint_common</test_depend>

<export>

<build_type>ament_cmake</build_type>

</export>

</package>

2.3开始编译

bash

cd ~/ws_offboard

colcon build --packages-select offboard_control

source install/setup.bash

编译成功以后终于可以开始运行状态机代码了

3运行状态机代码

开启终端1：运行gazebo（以下命令行中的export是针对Nvidia显卡，详情请看《基于ardupilot的gazebo仿真环境配置教程.docx》）

bash1

export __NV_PRIME_RENDER_OFFLOAD=1

export __GLX_VENDOR_LIBRARY_NAME=nvidia

export __VK_LAYER_NV_optimus=NVIDIA_only

gz sim -v4 -r ~/ardupilot_gazebo/worlds/iris_runway.sdf

正常运行结果如下图

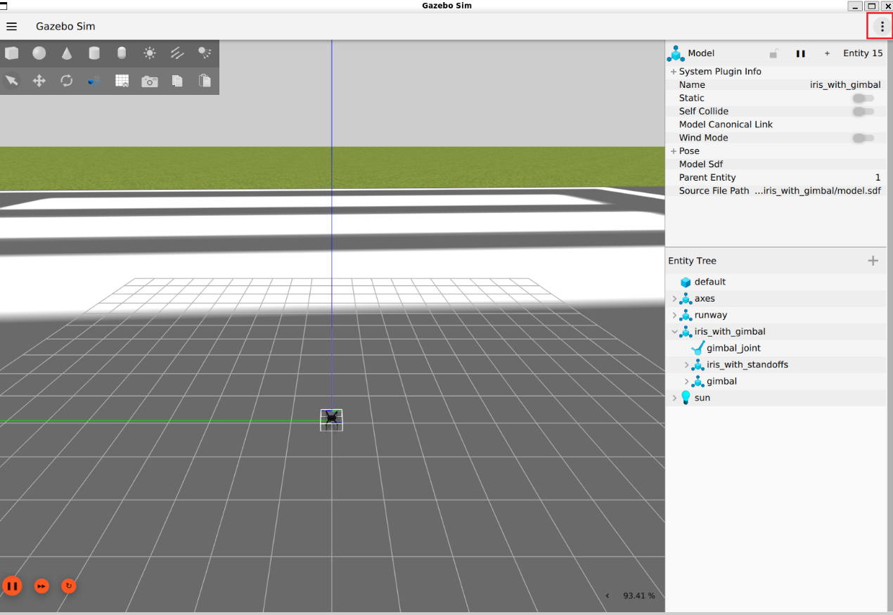
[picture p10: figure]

开启终端2：运行飞控ardupilot

bash2

cd ~/ardupilot/Tools/autotest

python3 ./sim_vehicle.py -v ArduCopter -f gazebo-iris --model JSON --map --console --out=udp:127.0.0.1:14550

正常运行结果：

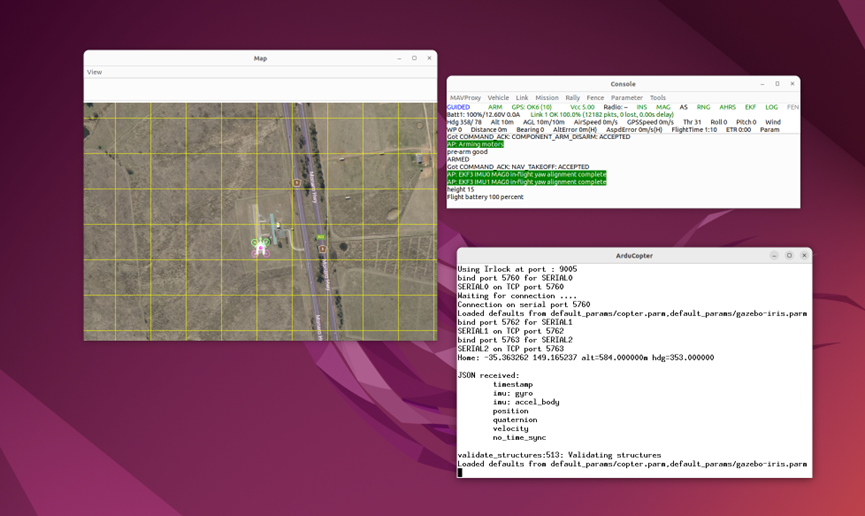
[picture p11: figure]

应该会出现如图三个窗口：Map（世界地图），Console(临时控制台，里面是你的状态机代码对应的输出)，ArduCopter

（如果发现Map里没有出现四翼无人机标志，请耐心等待）

开启终端3：运行mavros

bash3

ros2 run mavros mavros_node --ros-args -p fcu_url:=udp://:14550@

可能会出现关于mavros.distance_snesor的报错，这是一个有待解决的问题，但这并不影响运行状态机代码

开启终端4：运行状态机代码

bash4

source ~/ws_offboard/install/setup.bash

ros2 run offboard_control offb_node

如果一切顺利，你应该能看到无人机先起飞，再在（与地面平行的）平面内飞了一个矩形，最后降落回起飞点。

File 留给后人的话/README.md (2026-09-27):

# 属于我们的CUADC故事已经告一段落了，而属于你们的CUADC故事才刚刚开始！

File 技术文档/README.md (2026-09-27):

# 这里保存了经过实际验证稳定可靠的技术文档

# 特别鸣谢https://github.com/MOm0-000

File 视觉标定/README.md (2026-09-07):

# CUADC D435i 双投放视觉标定原理

## 1. 标定到底是在解决什么问题

这套标定的目标不是单纯让“相机画面看起来正”，也不是让识别框居中，而是建立一条完整、可验证的几何关系：

> **当视觉系统认为桶中心位于某个机体系坐标时，这个坐标必须与无人机真实的投放机构位置一致。**

对于双投放无人机，真正影响投放精度的不是飞控中心是否对准桶，而是：

- 1 号投放口的真实释放点是否位于桶中心上方；
- 2 号投放口的真实释放点是否位于桶中心上方；
- 相机看到的桶中心，是否被正确转换到了无人机机体系；
- 飞机姿态变化时，这些几何关系是否仍然成立。

因此整套标定可以拆成两个问题：

1. **相机外参标定**：D435i 看到的三维点，如何正确变成无人机机体系中的三维坐标；
2. **投放机构外参标定**：1 号、2 号投放口相对于无人机参考原点的真实位置到底在哪里。

最终状态机真正使用的关系可以抽象成：

```text
桶中心（相机坐标）
        ↓
相机外参
        ↓
桶中心（机体系）
        ↓
与 P1 / P2 真实投放口比较
        ↓
计算无人机应该移动到哪里
        ↓
真实释放口对准桶中心
```

---

## 2. 为什么“飞机中心对准桶”是不够的

无人机上至少存在几个不同的几何参考点：

- 飞控或导航系统使用的机体参考原点；
- D435i RGB 光学中心；
- 1 号投放机构真实释放点；
- 2 号投放机构真实释放点；
- 桶口中心。

这些点在空间中并不重合。

如果只让飞控中心悬停在桶中心正上方，那么只在一个非常特殊的条件下投放是准确的：

- 相机正好装在飞控中心；
- 投放机构也正好装在飞控中心；
- 飞机完全水平；
- 没有机械装配误差。

真实无人机显然不满足这些条件。

因此正确的思路不是：

> “让无人机中心对桶。”

而应该是：

> “根据当前姿态和投放口外参，反算无人机中心应该在哪里，才能让真实投放口位于桶中心上方。”

这也是整个标定工作的物理意义。

---

## 3. 三套坐标系必须先统一

视觉标定最容易出错的地方不是数值，而是坐标轴方向。

### 3.1 相机 Optical 坐标系

RealSense 彩色相机通常采用 Optical 约定：

```text
+X：图像向右
+Y：图像向下
+Z：相机光轴向前
```

D435i 在飞机上朝下安装时，“相机光轴向前”实际上就是朝地面。

---

### 3.2 无人机 FLU 坐标系

本项目正式视觉和投放状态机使用的是机体 FLU：

```text
+X：Forward，飞机前方
+Y：Left，飞机左侧
+Z：Up，飞机上方
```

因此：

- 右侧是负 Y；
- 下方是负 Z。

这套定义最终决定了投放口参数的正负号。

---

### 3.3 FRD 坐标系

一些独立标定工具使用 FRD：

```text
+X：Forward，前
+Y：Right，右
+Z：Down，下
```

FLU 与 FRD 的关系非常简单：

```text
X_frd =  X_flu
Y_frd = -Y_flu
Z_frd = -Z_flu
```

如果在不同模块之间交换标定结果，必须先明确到底使用哪一种机体系。

---

## 4. 当前相机安装方向应该怎样理解

这架飞机的 D435i 是向下看的。

根据当前实际使用的相机旋转关系，图像方向对应为：

```text
图像左侧   = 飞机前方
图像右侧   = 飞机后方
图像上方   = 飞机右侧
图像下方   = 飞机左侧
```

因此在标定画面中，如果方向正确：

```text
             飞机右
                ↑
                │
飞机前  ←──── 图像中心 ────→ 飞机后
                │
                ↓
             飞机左
```

这是开始任何标定前必须验证的第一件事。

如果方向错了，后续任何“调偏移”都只是在用错误的坐标系补偿错误，结果无法推广到真实飞行。

---

## 5. 相机外参是什么

相机外参本质上包含两部分：

### 5.1 旋转外参

回答：

> 相机的 X/Y/Z 轴，分别对应无人机的哪个方向？

数学上就是一个旋转矩阵：

```text
P_body = R_camera_to_body · P_camera + T
```

其中：

- `P_camera`：桶中心在相机坐标系中的位置；
- `R_camera_to_body`：相机坐标系到机体系的旋转；
- `T`：相机光学中心相对于机体原点的平移。

旋转外参主要由安装方向决定。

即使相机看起来“基本正”，只要有几度偏角，在 1 m 左右的视距上也会产生厘米级横向误差。

---

### 5.2 平移外参

回答：

> 相机光学中心相对于飞控参考点，在前后、左右、上下分别偏了多少？

例如：

- 相机在飞控前方，则 X 为正；
- 相机在飞控右侧，则 FLU 中 Y 为负；
- 相机在飞控下方，则 FLU 中 Z 为负。

平移外参是物理长度，不会因为飞行高度变化而按比例变化。

---

## 6. 为什么还需要 `camera_xy_bias`

机械尺测量和理论安装矩阵通常只能得到“名义外参”。

真实系统还会存在：

- 相机支架装配误差；
- RGB 光学中心与外壳参考点的偏差；
- 飞控参考原点和机架几何中心不完全一致；
- 深度到 RGB 对齐残差；
- 视觉目标中心定义与真实桶中心定义存在系统偏差。

因此工程上常再增加一个 XY bias：

```text
最终机体坐标
= 理论刚体变换结果
+ XY 残差修正
```

它不是替代刚体外参，而是用于吸收小范围、稳定的系统性残差。

如果两个投放点都表现为“几乎同方向、同大小偏移”，通常适合用 XY bias 修正。

---

## 7. 投放口外参是什么

投放口外参描述的是：

> 当飞机处于标准机体系姿态时，真实释放点相对于机体参考原点的位置。

每个投放口都有一个三维向量：

```text
P1 = [X1, Y1, Z1]
P2 = [X2, Y2, Z2]
```

在 FLU 中：

- X 正：向机头；
- Y 正：向左；
- Z 正：向上。

因此实际投放机构位于机体下方时，Z 通常是负数。

双投放系统绝不能默认两个投放口完全对称。

因为实际装配中可能存在：

- 舵机支架位置不同；
- 水瓶夹持中心不同；
- 释放瞬间真实出口与舵机轴心不同；
- 左右机构加工和安装误差不同。

所以 P1、P2 应该分别实测，而不是简单使用镜像值。

---

## 8. 为什么用“铅垂线 + 桶中心”做标定

这是这套方法最关键的物理基准。

标定时无人机保持静止、水平、不解锁，从真实投放口向下做铅垂线：

```text
真实投放口
    │
    │ 铅垂线
    ↓
  桶中心
```

只要桶中心位于该投放口真实垂线正下方，就获得了一个“真值条件”：

> 桶中心的真实机体 XY，应该等于这个投放口的机体 XY。

这就把视觉测量值和物理真实位置直接关联起来。

例如：

```text
视觉测得：桶中心 = (Xm, Ym)
真实投放口：P1 = (X1, Y1)
```

那么残差就是：

```text
ΔX = X1 - Xm
ΔY = Y1 - Ym
```

这比“看画面大概对不对”可靠得多。

---

## 9. 准星可视化的原理

可视化不是为了好看，而是把三维几何关系投回到二维图像中，方便人工判断。

画面通常包含三种信息：

### 9.1 绿色 TARGET

代表视觉算法最终认为的桶中心。

它不是简单的检测框中心，而应当是经过：

```text
目标分割
→ 椭圆/几何中心估计
→ 深度获取
→ 相机三维反投影
→ 相机到机体系外参变换
```

之后得到的最终目标位置。

所以绿色 TARGET 应该代表“真正交给状态机使用的桶中心”。

---

### 9.2 P1 准星

表示：

> 如果桶中心正好位于 1 号真实投放口铅垂线下方，那么按当前相机外参，它应该出现在图像中的什么位置。

---

### 9.3 P2 准星

同理，表示 2 号真实投放口铅垂线在当前目标平面上的理论图像位置。

因此标定的直观目标就是：

```text
物理上：桶在 P1 正下方
画面上：TARGET 与 P1 重合
```

或者：

```text
物理上：桶在 P2 正下方
画面上：TARGET 与 P2 重合
```

---

## 10. 为什么 P1/P2 准星不是固定像素

这是非常重要的一点。

投放口是固定的真实机械偏移，例如几厘米。

但同样几厘米的真实偏移，在图像中对应多少像素，取决于相机与桶之间的距离。

近距离：

```text
相同 5 cm 机械偏移
→ 图像上像素差很大
```

远距离：

```text
相同 5 cm 机械偏移
→ 图像上像素差变小
```

因此正确的准星应该实时根据：

- 相机内参；
- 当前相机外参；
- 当前目标深度；
- P1/P2 机械坐标；

重新投影，而不能简单写死成“中心左上 30 像素”“右下 40 像素”。

---

## 11. 为什么使用两个投放口可以区分“平移误差”和“旋转误差”

这是双点标定的核心价值。

假设 P1 和 P2 都测量一次。

### 情况 A：P1、P2 都向同一方向偏

例如：

```text
P1 都偏右 3 cm
P2 也偏右 3 cm
```

这通常意味着：

- 相机 XY 平移不准；
- 或存在统一的视觉 XY bias。

这类误差适合通过平移修正。

---

### 情况 B：P1 和 P2 的误差方向相反

例如：

```text
P1 偏左
P2 偏右
```

这更像是：

- 相机绕 Z 轴存在 yaw 安装误差；
- 或两个投放口的机械位置本身不准确。

因为旋转误差会随着点相对于参考原点的位置不同而产生不同方向的偏差。

---

### 情况 C：P1 很准，P2 明显不准

这时不应该继续修改全局相机外参。

因为如果相机外参本身错误，P1、P2 通常都会受影响。

更合理的怀疑对象是：

- P2 机械外参测量错误；
- 2 号投放机构真实释放点和理论轴心不一致；
- 2 号机构安装存在个体误差。

此时应该单独修 P2，而不是破坏已经准确的 P1。

---

## 12. 为什么不能只用一个点标定全部外参

单点只能确定平移，不能可靠确定二维旋转。

原因是：

```text
一个点的位置误差
可以由平移解释
也可以由旋转 + 平移解释
```

只有两个空间上不同的已知点，才能看出：

- 视觉测得的点间方向是否正确；
- 点间距离是否合理；
- 是否存在旋转误差。

因此双投放系统天然适合做两点标定。

---

## 13. 标定高度为什么重要

严格来说，相机的刚体外参不应该随高度变化。

但工程上，标定高度仍然很重要，因为：

- 微小的相机 roll/pitch/yaw 安装误差，在距离更远时会放大成更大的横向误差；
- 深度测量误差随距离变化；
- 桶的几何中心估计在不同尺度下可能有轻微偏差；
- 地面反光、桶边缘深度质量和遮挡也会变化。

因此最合理的原则是：

> **尽量在正式投放的工作高度附近完成最终验证。**

如果正式 RELEASE 高度是 1.3 m，那么最好在 1.3 m 附近做最终 P1/P2 验证。

---

## 14. 为什么不能把 0.9 m 标定结果简单按比例换算到 1.3 m

这是一个常见误区。

相机平移外参本质上是机械长度：

```text
相机比飞控前 3 cm
```

无论飞机飞 0.9 m 还是 1.3 m，这个 3 cm 都不会变成 4.3 cm。

因此：

> 平移外参不能按飞行高度比例缩放。

会随距离产生明显变化的是“角度误差导致的横向投影误差”。

例如一个很小的安装角：

```text
横向误差 ≈ 距离 × tan(角度误差)
```

所以更高高度下，如果出现新的 XY 残差，应重新检查角度误差，而不是直接按高度比例放大 bias。

---

## 15. Z 方向应该怎样标定

Z 方向与 XY 不同。

视觉节点最终识别的目标平面必须明确到底是什么：

- 桶底；
- 地面；
- 桶口；
- 桶壁上缘；
- 某个深度补偿后的虚拟平面。

本项目标定时的核心判断是：

```text
飞机参考点离地高度
- 视觉测得的 |body_z|
≈ 桶口离地高度
```

如果这个关系与实际桶高基本一致，说明：

- 深度尺度正确；
- 目标平面定义正确；
- 相机 Z 偏移基本合理。

当 Z 已经达到毫米或厘米级一致时，不应该为了修 XY 再去修改深度尺度或 Z 偏移。

---

## 16. 为什么“先固定相机，再调投放口”很重要

标定参数很多，但不能同时乱调。

推荐顺序是：

### 第一步：验证坐标轴方向

确认：

```text
图像左 = 前
图像上 = 右
```

以及目标移动方向与机体系定义一致。

---

### 第二步：验证 Z

确认目标平面深度与实际高度关系合理。

---

### 第三步：用 P1/P2 判断相机 XY/yaw

如果两个点都存在统一偏差，先修相机外参。

---

### 第四步：固定相机外参

一旦 P1 已经准确，且整体几何关系合理，就不要再频繁修改相机参数。

---

### 第五步：分别修 P1/P2 机械外参

如果只剩单个投放机构存在残差，就把它视为机构个体误差处理。

这能防止出现：

```text
为了修 P2
→ 改坏相机
→ P1 又错
→ 再修 P1
→ 整套参数来回漂移
```

---

## 17. 推荐的完整标定流程

### 阶段 A：准备

- 卸桨；
- 飞机不解锁；
- 机体保持水平；
- D435i 正常启动；
- 使用正式视觉模型和正式深度处理方式；
- 使用正式比赛曝光策略；
- 确认画面方向。

---

### 阶段 B：检查相机坐标

移动桶：

- 向飞机前方移动，视觉 X 应增大；
- 向飞机左侧移动，FLU Y 应增大；
- 桶位于飞机下方，FLU Z 应为负。

方向错误时，停止后续标定。

---

### 阶段 C：P1 标定

1. 将桶中心放在 P1 真实释放点铅垂线下；
2. 保持飞机和桶静止；
3. 连续采集若干秒；
4. 使用中位数而不是单帧；
5. 比较视觉机体 XY 与 P1 真实 XY。

---

### 阶段 D：P2 标定

完全相同地测量 P2。

---

### 阶段 E：误差分类

比较 P1、P2：

```text
同方向同大小 → 相机平移/bias
反向或角度型 → 相机 yaw
只有一边错     → 投放机构个体外参
```

---

### 阶段 F：重新验证

任何参数修改后都必须重新验证：

```text
P1 → P2 → P1
```

而不是只测一次就结束。

这样可以确认没有“修好一个、改坏另一个”。

---

## 18. 为什么使用中位数而不是单帧

视觉结果会受到：

- 深度噪声；
- segmentation 边缘抖动；
- RGB-D 对齐抖动；
- 目标椭圆拟合波动；
- USB/处理延迟；
- 光照变化；

影响。

所以单帧可能偶然很好，也可能偶然很差。

固定飞机和桶后，连续采样 3～5 秒，取：

```text
median(X)
median(Y)
median(Z)
```

可以有效抑制异常值。

同时用 MAD（Median Absolute Deviation，中位绝对偏差）评估稳定性。

MAD 很小意味着：

> 这不是“偶然刚好对”，而是视觉结果稳定地落在这个位置。

---

## 19. 如何判断标定质量

建议至少看四个层面。

### 19.1 方向正确

任何轴方向不能错。

---

### 19.2 单点稳定

静态条件下 MAD 应尽可能小。

---

### 19.3 P1/P2 残差

最终希望：

```text
|ΔX| ≤ 5 mm
|ΔY| ≤ 5 mm
```

能进入 2～3 mm 更好，但不必为了追求 1 mm 而过度拟合。

真实飞行中还会存在：

- 姿态变化；
- 风；
- 飞控位置估计误差；
- 桶识别误差；
- 舵机释放动态；

所以静态标定追求“稳定、可重复”比追求某一帧绝对零误差更重要。

---

### 19.4 跨高度验证

如果条件允许，可以在：

- 1.0 m；
- 1.3 m；
- 1.5 m；

附近做验证。

如果误差随高度近似线性增大，通常提示存在角度外参误差。

如果误差基本恒定，通常更像平移/bias。

---

## 20. 标定与姿态补偿的关系

静态标定通常在飞机水平时完成。

但真实飞行中，飞机会出现 roll / pitch。

投放口本身是固定在机体上的，所以它在世界坐标系中的位置应该是：

```text
P_release_world
=
P_vehicle_world
+
R_vehicle · P_release_body
```

也就是说：

- 标定解决的是 `P_release_body` 是否准确；
- 状态机姿态补偿解决的是当前 `R_vehicle` 如何把它旋转到世界坐标。

二者缺一不可。

标定再准，如果飞行时忽略 roll/pitch，依然可能投偏。

姿态补偿再完善，如果投放口外参本身是错的，也只是在“精确地补偿一个错误的机械位置”。

---

## 21. 为什么这套方法适合 CUADC 双投放任务

比赛投放任务的真正难点不是实现视觉识别，而是把：

```text
视觉
飞控
机架
投放机构
真实目标
```

放进同一个几何框架。

这套方法的优势是：

1. 使用真实投放机构作为物理基准；
2. 不依赖纯理论尺寸；
3. P1/P2 可以分别标定；
4. 能区分相机误差和机构误差；
5. 能直接与状态机的刚体投放补偿对应；
6. 标定结果有明确的物理单位（m），而不是经验像素；
7. 可以在正式投放高度附近验证；
8. 可重复、可量化、可复现。

---

## 22. 最终应该形成怎样的参数体系

成熟之后，整架无人机应只保留三类稳定参数。

### A. 相机外参

描述：

```text
D435i optical → aircraft body
```

包括：

- 旋转；
- XYZ 平移；
- 必要的稳定 XY bias。

---

### B. P1 机械外参

描述 1 号真实投放点相对于机体原点的位置。

---

### C. P2 机械外参

描述 2 号真实投放点相对于机体原点的位置。

P1/P2 不强求机械对称，而以实际投放效果和物理标定为准。

---

## 23. 一句话理解整个标定

整套方法的本质可以压缩成一句话：

> **先让视觉正确地知道“桶在哪里”，再让系统正确地知道“两个瓶子真正从哪里掉下来”，最后让状态机根据飞机实时姿态，把真实投放口而不是飞机中心移动到桶中心正上方。**

因此，视觉准星只是一个可视化工具；真正的标定对象始终是：

```text
相机三维坐标
↔
机体真实几何
↔
投放机构真实释放点
```

当这三者统一以后，后续搜索高度、对准速度、姿态补偿、释放门限才建立在正确的几何基础上。

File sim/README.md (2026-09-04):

# 仿真工程区

`sim/` 用于集中归档和管理本仓库中的 CUADC 仿真工程。这里保留不同用途、不同阶段的仿真实现，便于独立查阅、复现和对比；各工程的具体安装、构建与运行方法以其目录内的 `README.md` 为准。

## 目录说明

| 目录 | 作用 |
| --- | --- |
| `cuadc_hazard_recognition_sim-v0.2.0/` | 危险品侦察仿真 v0.2.0，包含 ROS 2、Gazebo Sim、ArduPilot SITL、MAVROS、ONNX 视觉识别以及覆盖搜索状态机，用于较完整地验证危险品侦察流程。 |
| `cuadc_hazard_recognition_sim/` | 轻量级危险品标识识别场景，主要用于单独验证随机场景、危险品标识纹理和固定下视 RGB-D 相机，不包含无人机、ArduPilot、MAVROS 或任务状态机。 |
| `cuadc_sim/` | 面向多旋翼无人机侦察与救援赛项的全流程仿真环境，覆盖场地、无人机、投放区、侦察区、虚拟投放和危险品标识等内容；其 ROS 2 包名为 `cuadc_rescue_sim`。 |

## 使用注意事项

- `cuadc_hazard_recognition_sim-v0.2.0/` 和 `cuadc_hazard_recognition_sim/` 的 ROS 2 包名均为 `cuadc_hazard_recognition_sim`，它们是不同阶段的实现，不能同时加入同一个 `colcon` 工作区构建。使用时请选择其中一个。
- 本目录首先承担集中归档作用。建议把需要运行的单个工程复制或链接到 ROS 2 工作区的 `src/` 下，再按该工程自己的文档构建。

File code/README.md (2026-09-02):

# CUADC Code

本目录用于整理和记录团队历年 CUADC（中国大学生飞行器设计创新大赛）相关代码。

## 目录结构

```text
code/
├── 2025code/        # 2025 年比赛代码及历史版本
└── 2026code/        # 2026 年比赛代码
    ├── 状态机/      # 无人机自主任务状态机
    └── 视觉/        # 目标检测、定位与视觉处理
```

2025 年代码主要围绕ROS1展开，保留ROS1节点风格。
2026 年代码主要围绕ROS2展开，同时，全流程运动学控制和轨迹规划更加复杂。

仓库中的部分代码为整理后的开源版本，主要用于学习和交流。实际飞行参数、硬件配置及部分比赛相关算法需要根据具体平台重新标定和调整。

> ⚠️ 请勿未经测试直接用于真机飞行。建议先完成代码检查、仿真测试及无桨测试。

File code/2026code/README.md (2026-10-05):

# 2026 年备赛代码说明

## 文件夹说明

此文件夹用于储存 2026 年多旋翼无人机侦察与救援项目的主要备赛代码。

相比 2025 年代码，2026 年的开发环境由 **Ubuntu 20.04 + ROS 1** 更新为：

* Ubuntu 22.04
* ROS 2 Humble
* MAVROS
* ArduPilot / ArduCopter
* Gazebo Harmonic

2025 年代码仍然具有较高的参考价值，尤其是状态机设计、视觉引导、目标搜索和投放流程等部分。但是 ROS 1 与 ROS 2 的节点、话题、服务和编译方式存在较大差异，移植时不要直接复制代码，应当先理解原有逻辑，再按照 ROS 2 的接口重新实现。

目前 2026 年代码主要按照功能划分为 `状态机` 和 `视觉` 两部分。后续版本建议继续采用“模块名称 + 版本号”的方式命名，例如 `状态机1.0`、`视觉1.1`，并在每个版本开头注明代码功能、仿真验证情况和真机验证情况。

---

## 目录结构

```text
2026code/
├── 状态机/
│   ├── README.md
│   ├── cuadc_full_mission_node_1.cpp
│   ├── cuadc_full_mission_node_2.cpp
│   ├── cuadc_full_mission_node_3_v0_public.cpp（北部赛区冠军机组代码）
│   ├── cuadc_full_mission_node_3_v1_public.cpp
│   ├── cuadc_full_mission_node_3_v2_public.cpp
│   ├── cuadc_full_mission_node_3_v3_public.cpp
│   ├── cuadc_full_mission_node_3_v4_public.cpp
│   ├── cuadc_full_mission_node_3_v5_public.cpp
│   ├── cuadc_full_mission_node_3_v6_public.cpp
│   ├── cuadc_full_mission_node_3_v7_public.cpp
│   ├── offb_node.cpp（实现自动飞行的第一步，作为新机环境验证较为合适）
│   ├── recon_state_machine_node_1.cpp
│   ├── takeoff_drop_land_node_1.cpp
│   ├── takeoff_drop_land_node_2.cpp
│   └── ws_offboard/
|       ├── ws_offboard_2026_6_20
|       ├── ws_offboard_2026_8_20
│       └── ws_offboard_2026_10_05（加入了不依赖磁罗盘的航向确认逻辑，为整体流程的倒数第二版，在学校能实现较为稳定的1300分）
│
└── 视觉/
    ├── README.md
    └── 视觉1.0/
    |   ├── dangerous_target.onnx
    |   ├── labeling.py
    |   ├── labels.docx
    |   └── single_demo_en.py
    └── 视觉2.0/drop
    |    ├── basket_detect_seg.pt
    |    └── basket_detect_seg.py
    └── 视觉3.0/
    |   ├── basket_detect_seg_analysis.py
    |   ├── basket_v3.onnx
    |   └── basket_v3.pt
    └── 视觉4.0/

## 注意事项

自动飞行代码必须先经过 SITL 仿真验证，再进行真机测试。

真机测试前应当确认：

* 飞控模式和固件正确；
* MAVROS 已连接；
* 本地位置数据正常；
* 高度和坐标系方向正确；
* 起飞区域无人员和障碍物；
* 遥控器能够随时切换模式并人工接管；
* 已准备紧急降落和上锁命令；
* 首次测试应拆除桨叶检查服务和状态切换逻辑。

不要在没有安全员、没有人工接管手段或坐标系尚未验证的情况下直接运行自动飞行程序。

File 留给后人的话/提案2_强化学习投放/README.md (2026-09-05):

# CUADC 投放阶段强化学习方案草案

这是一套针对 [Accelerate11/2026CUADC](https://github.com/Accelerate11/2026CUADC) 的**本地、可运行研究草案**。目标是利用现有 D435i 视觉和飞控里程计，在接近桶口后学习投放时机，并逐步研究小幅水平修正。**不增加传感器**。搜索、选桶、起降、航线、姿态控制仍由原任务状态机和飞控负责。

用户目前给出的约束是“投放阶段采用强化学习、不增加传感器”；具体算法与动作范围尚未限定。因此这里把第一版限定为**近悬停、单个已锁定桶、单瓶投放**，先建立能复现的试验，再决定是否扩大动作范围。

## 先运行

基础部分只需 **Python 3.10+**，不需要 ROS、Gazebo、GPU 或任何第三方包。已在 Windows 的 Python 3.14 和 3.12 上验证；Ubuntu 可以把命令中的 `python` 换成 `python3`。

在本文件所在目录打开终端：

```bash
python scripts/run_quickstart.py
```

此命令依次运行测试、36 组弹道计算、6000 回合 Q-learning、两套各 300 场的对比评估、两份 HTML 回放及遥测接口示例。所有生成文件保存在 `outputs/`。双击 `outputs/demo_q.html` 即可播放；拖动时间轴可查看释放位置与最终落点。

也可以先只看一场基线投放：

```bash
python scripts/demo.py --policy hover --seed 2026 --out outputs/demo_hover.html
```

交付目录的 `examples/results/` 保存了本次真实运行的模型、评估和回放快照，不需要先训练即可阅读。原始工作目录还保留 `outputs/`。默认种子 2026 的 Q-learning 回放是一场擦边未命中的案例，方便观察失败原因，没有筛选成只展示成功。

## 方案具体做什么

```mermaid
flowchart LR
    A[现有 D435i 桶口识别] --> C[曝光时刻对齐与坐标转换]
    B[现有 MAVROS 里程计] --> C
    C --> D[投放策略]
    D --> E[候选水平修正和释放请求]
    E --> F[原状态机的稳定条件与投放流程]
    F --> G[现有飞控和投放机构]
```

目录中的实际硬件接口目前止于**影子决策**：输入已有观测、输出候选决策及理由。图中后半段是接入设计，尚未写入原状态机。不会连接飞控或发出舵机命令。

| 实现 | 学习的动作 | 用途 |
|---|---|---|
| Q-learning，已实现 | 等待 / 请求投放 | 最小闭环；不依赖深度学习框架 |
| PPO，已实现可选入口 | 两维限幅速度残差 + 请求投放 | 在原对准控制基础上研究微调 |
| 悬停基线 | 对准后低速稳定，再投放 | 判断 RL 是否有实际收益 |
| 弹道基线 | 按速度、高度与标称延迟预测落点 | 判断学习是否优于简单模型 |

这里的“基线”是本目录自行实现的简化控制器，并非原项目实飞算法的复制。Q-learning 的二维移动由固定对准控制器完成，**学习的只有投放时机**；PPO 才会学习水平微调。算法、观测及奖励详见 [方案说明](docs/01_方案设计.md)。

## 与你现有项目的对应关系

2026-09-05 通过 GitHub 当前目录接口核对到：

- `code/2026code/状态机/cuadc_full_mission_node_3_v2_public .cpp`：注意 `public` 后有空格；包含 `ALIGN`、`RELEASE`，订阅 `/mavros/local_position/odom` 与 `/perception/drop_buckets_body`。
- `code/2026code/视觉/视觉2.0/drop/basket_detect_seg.py`：使用 D435i、YOLO 分割、桶口椭圆及深度。该脚本本身主要录像和打印，**不能直接假设它已经发布状态机需要的 ROS 话题**。
- `sim/cuadc_sim/`：Gazebo/ArduPilot/ROS 2 仿真。虚拟裁判按飞机当前位置评分，尚未计算瓶子的真实下落轨迹。本草案补充轻量弹道试验，但没有修改该仿真包。

参考的 [状态机公开文件](https://github.com/Accelerate11/2026CUADC/blob/main/code/2026code/%E7%8A%B6%E6%80%81%E6%9C%BA/cuadc_full_mission_node_3_v2_public%20.cpp) 明确省略了实机外参、弹道参数、同步和正式门限。这些内容无法从公开仓库推断，本草案中的相关数值都是**可修改的演示假设**。[来源与核对记录](docs/05_来源与边界.md) 列出了具体文件和 blob SHA。

## 仿真范围与参数

默认桶口直径 **25 cm**；另有 15 cm、20 cm 配置，来自仓库 [场景配置](https://github.com/Accelerate11/2026CUADC/blob/main/sim/cuadc_sim/config/scene.yaml)，不是对最新比赛规则的独立确认。

默认假设瓶体有效半径 3 cm、余量 0.5 cm，所以有效命中半径为 `12.5 - 3 - 0.5 = 9 cm`。默认高度 `1.2 m` 是**投放口到桶口平面的垂直高度**，不能直接使用起飞相对高度替代。

| 配置文件 | 场景 |
|---|---|
| `configs/nominal.json` | 无风、机构参数固定；保留观测噪声 |
| `configs/randomized.json` | 默认域随机化：风、延迟、观测误差、深度噪声 |
| `configs/stress.json` | 更大风、噪声、视觉延迟和丢帧 |
| `configs/vision_loss.json` | 全程视觉失效，应超时而不释放 |
| `configs/bucket_15cm.json` / `bucket_20cm.json` | 仓库较小桶口尺寸 |
| `configs/warmup_large_bucket.json` | 50 cm 教学桶，仅用于热身，不对应仓库桶尺寸 |

配置文件采用 JSON，只覆盖列出的字段，其余取 `drop_rl/config.py` 默认值。每次训练、评估会保存完整展开配置。

模拟了飞机水平一阶速度响应、载荷继承速度、机构延迟、水平线性空气阻力、视觉曝光延迟和丢帧。**未模拟六自由度、翻滚、下洗、撞沿弹跳、落桶后滞留、目标误识别和全场航线**。命中表示瓶体截面在首次穿越桶口平面时落入有效半径，不等价于实物成功留桶。详见 [仿真说明](docs/02_仿真与参数.md)。

## 分步训练与评估

```bash
python scripts/ballistic_sweep.py
python scripts/train_q.py --config configs/randomized.json --episodes 6000 --seed 11 --out outputs/q_policy.json
python scripts/evaluate.py --model outputs/q_policy.json --episodes 300 --seed 80000000 --out outputs/evaluation
python scripts/evaluate.py --model outputs/q_policy.json --config configs/stress.json --episodes 300 --seed 81000000 --out outputs/stress
python scripts/evaluate.py --model outputs/q_policy.json --config configs/bucket_15cm.json --episodes 300 --seed 83000000 --out outputs/bucket15
python scripts/demo.py --policy q --model outputs/q_policy.json --seed 2026 --out outputs/demo_q.html
python scripts/demo.py --policy q --config configs/vision_loss.json --out outputs/vision_loss.html
```

小桶评估示例刻意使用同一个 25 cm 训练模型，属于尺寸外推试验。要为小桶单独训练，将 `train_q.py` 的 `--config` 换成对应文件并另存模型。

评估使用相同种子为四种策略生成相同初始条件与外部扰动，所有策略只能读取 `Observation`。`info` 和回放中的落点真值只用于评分。命中率分母包含超时与越界；平均落点误差只统计已释放回合，因此同时报告释放率、超时、P90 和 95% Wilson 区间。

本次默认场景 300 场实测：悬停基线 **92.7%**，Q-learning **83.7%**，弹道基线 **66.3%**，随机策略 **16.3%**。这证明代码完成训练评估闭环，**尚不能证明 RL 优于悬停规则**。压力场景仍明显退化，详见 [运行结果](docs/04_实验结果.md)。

## 可选 PPO

建议 Python 3.10–3.12，单独虚拟环境。PPO 不影响基础版本。

Windows PowerShell：

```powershell
py -3.12 -m venv .venv-ppo
.\.venv-ppo\Scripts\python.exe -m pip install -r requirements-ppo.txt
.\.venv-ppo\Scripts\python.exe scripts/train_ppo.py --steps 200000 --out outputs/ppo_policy
.\.venv-ppo\Scripts\python.exe scripts/evaluate_ppo.py --model outputs/ppo_policy.zip --episodes 300
```

Ubuntu：

```bash
python3 -m venv .venv-ppo
.venv-ppo/bin/python -m pip install -r requirements-ppo.txt
.venv-ppo/bin/python scripts/train_ppo.py --steps 200000 --out outputs/ppo_policy
.venv-ppo/bin/python scripts/evaluate_ppo.py --model outputs/ppo_policy.zip --episodes 300
```

`train_ppo.py` 会先运行 SB3 环境检查，再保存模型、训练监控与版本元数据。输出的三个数依次为水平速度残差 x、y 和释放请求；残差范数上限默认为 0.15 m/s，总水平指令范数上限为 0.6 m/s。高度固定，由原任务控制维持。

本次已实际验证约 3 万步 PPO 训练和独立评估；具体依赖版本记录在 `requirements-ppo-tested.txt`，可用它代替范围依赖文件复现此环境。

评估时需显式传入与训练一致的 `--config`；省略表示默认配置。`evaluate_ppo.py` 同时运行两个基线，物理指标可直接比较；PPO 训练额外包含残差动作代价，训练回报与评估基础回报不要混为一谈。

## 接回项目的步骤

1. 标定现有相机到机体、投放口到机体的外参，用已有视频和日志估计延迟、深度误差和响应时间。
2. 在原状态机中对已有视觉与里程计做时间同步、坐标转换和目标身份锁定；输出本目录约定的快照。
3. 先运行 `integration/replay_telemetry.py` 或可选 ROS 2 影子节点，只比较候选决策和原策略。
4. 将候选水平修正与投放请求接入原 `ALIGN/RELEASE`，由原状态机保持唯一控制输出与舵机执行责任。
5. 经过 Gazebo/SITL、机构台架及受控低速投放，对同样测试条件比较误差与成功率；没有可靠优势就继续保留原规则。

[接入说明与字段表](integration/README.md) 提供坐标、时间、数据字段、状态转换和缺失信息处理细节。所需数据全部来自已有视觉、飞控和程序状态；没有增加风速计、外部定位系统、落点传感器或释放检测传感器。

## 文件夹结构

```text
cuadc_drop_rl/
├── README.md
├── configs/                    # 可覆盖的仿真配置
├── docs/                       # 方案、模型、落地、结果、来源
├── drop_rl/
│   ├── config.py               # 参数与校验
│   ├── physics.py              # 下落与水平运动
│   ├── observation.py          # 策略可见观测、门控、固定对准控制
│   ├── env.py                  # 二维投放仿真
│   ├── policies.py             # 基线与 Q-learning
│   ├── gym_env.py              # PPO 环境
│   ├── integration.py          # 坐标转换与单次候选请求
│   └── replay*.{py,html}       # 离线可视化
├── scripts/                    # 运行、训练、评估、回放、归档
├── integration/                # 遥测回放和可选 ROS 2 影子节点
├── examples/
│   ├── telemetry.jsonl         # 已有传感器数据接口示例
│   └── results/                # 本次运行的可复查快照
├── tests/                      # 标准库 unittest；可选 Gym 检查
├── requirements.txt            # 基础版本无第三方依赖
├── requirements-ppo.txt        # 可选依赖范围
└── outputs/                    # 本机生成结果，不纳入常规版本管理
```

## 常见问题

- **是否能直接飞？** 现在可以直接运行仿真、训练和日志回放；接入实机需要你的标定、时间同步、状态机整合与验证。本目录没有实机执行入口。
- **缺少深度怎么办？** 使观测无效，暂停释放并交回原状态机处理；不以仿真真值补齐，也不要求新增测距器。
- **没有测风能补偿风吗？** 可从现有运动历史研究间接估计，但飞机表现不能唯一确定瓶子受风。当前策略没有风输入，无法保证强风或突发风下精确补偿。
- **只有相机图像就够吗？** 本草案沿用仓库现有 RGB-D 和飞控估计；不训练端到端图像网络，视觉识别沿用现有代码。
- **PPO 缺包？** 使用其单独虚拟环境并安装 `requirements-ppo.txt`；基础命令不需要安装。
- **为什么没有完整克隆原仓库？** 这里只交付新增方案文件夹，并记录核对过的来源；没有修改或推送 GitHub。

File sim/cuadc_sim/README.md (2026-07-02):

# CUADC Simulation

面向 2026 中国大学生飞行器设计创新大赛“多旋翼无人机侦察与救援”赛项的 Gazebo + ArduPilot SITL + ROS2 仿真环境。

本仓库目标是复现比赛场地和任务流程，用于训练与验证：

- 多旋翼全自动飞行流程
- 投放区圆筒定位与虚拟投放
- 侦察区危险化学品标识识别
- 下视 RGB-D 相机接口
- 后续实机 D435i 与投放机构的软件接口迁移

当前版本不模拟水瓶真实下落，不模拟舵机机械结构，只提供统一的虚拟投放事件 `/drop_controller/release`。实机阶段可将该事件替换为飞控 PWM 或舵机控制输出。

## 当前状态

已完成：

- 独立 ROS2 包 `cuadc_rescue_sim`
- 规则尺寸场地：起降区、起飞线、投放区、侦察区
- 派生 Iris 模型 `iris_d435i`
- 下视 RGB-D 相机传感器
- 3 个随机投放桶
- 5 个随机侦察桶
- 3 个随机危险化学品标识贴图
- 附件 11 的 10 类真实危险化学品标识纹理
- Gazebo world 自动生成脚本
- 虚拟投放裁判节点骨架
- 任务演示节点骨架

## 目录

```text
cuadc_rescue_sim/
├── config/                 # 场景、任务、桥接配置
├── docs/                   # 详细教程和归档说明
├── launch/                 # ROS2 launch
├── models/                 # Gazebo 模型和纹理
├── scripts/                # 生成、启动、停止、归档脚本
├── src/                    # ROS2 C++ 节点
├── worlds/                 # Gazebo world
├── CMakeLists.txt
├── package.xml
└── README.md
```

## 快速开始

构建：

```bash
cd ~/cuadc_ws
source /opt/ros/humble/setup.bash
colcon build --packages-select cuadc_rescue_sim
source install/setup.bash
```

生成一轮随机场景：

```bash
cd ~/cuadc_ws/src/cuadc_rescue_sim
python3 scripts/generate_scene.py
cd ~/cuadc_ws
colcon build --packages-select cuadc_rescue_sim
```

启动 Gazebo：

```bash
cd ~/cuadc_ws
source install/setup.bash
ros2 launch cuadc_rescue_sim cuadc_sim.launch.py
```

另开终端启动 ArduPilot SITL：

```bash
cd ~/ardupilot/Tools/autotest
python3 ./sim_vehicle.py -v ArduCopter -f gazebo-iris --model JSON --map --console --out=udp:127.0.0.1:14550
```

后台启动 Gazebo：

```bash
~/cuadc_ws/src/cuadc_rescue_sim/scripts/start_cuadc_sim.sh
```

停止 Gazebo：

```bash
~/cuadc_ws/src/cuadc_rescue_sim/scripts/stop_cuadc_sim.sh
```

## 详细文档

- [完整配置教程](docs/SETUP.md)
- [配置文件说明](docs/CONFIGURATION.md)
- [规则映射说明](docs/RULE_MAPPING.md)
- [GitHub 归档说明](docs/GITHUB_ARCHIVE.md)

## 重要路径

```text
~/cuadc_ws/src/cuadc_rescue_sim
~/cuadc_ws/src/cuadc_rescue_sim/worlds/cuadc_rescue_single.sdf
~/cuadc_ws/src/cuadc_rescue_sim/config/generated_scene.yaml
~/cuadc_ws/src/cuadc_rescue_sim/models/hazard_marker/materials/textures
```

## 上游来源说明

`models/iris_d435i` 与 `models/iris_d435i_airframe` 基于本机 `~/ardupilot_gazebo` 中的 Iris 模型派生，仅增加下视 RGB-D 相机并修改模型命名。上游 `ardupilot_gazebo/LICENSE.md` 为 LGPL v3，归档到 GitHub 时请保留来源说明。

危险化学品标识纹理来自比赛附件 11，用于本赛项仿真训练。

## 运行效果
68edb154916b6c0f021813433ca1e971
a864ee056c372db0712d3d0863653156

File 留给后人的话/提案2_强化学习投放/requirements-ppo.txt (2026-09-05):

numpy>=1.24,<3
gymnasium>=1.0,<2
stable-baselines3>=2.4,<3
# 建议 Python 3.10–3.12；PyTorch 由 stable-baselines3 安装。

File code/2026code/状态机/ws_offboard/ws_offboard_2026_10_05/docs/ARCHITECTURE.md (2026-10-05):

# 包职责与通信接口

本版按职责拆分原包的构建和安装边界。任务内部的导航、投放、状态检查仍在原 C++ 节点中，以保留原飞机的任务行为。

```mermaid
flowchart LR
    B[cuadc_bringup 启动与参数] --> M[cuadc_mission 任务状态机]
    B --> P[cuadc_perception 桶视觉]
    B --> T[cuadc_tools 消息频率与遥测]
    C[D435i 相机] --> P
    P -->|桶位置与视觉心跳| M
    M -->|设定点与飞控服务| V[MAVROS]
    V --> F[ArduPilot 飞控]
    V -->|位置、模式与姿态| M
    V --> T
```

| 包 | 构建类型 | 主要内容 |
| --- | --- | --- |
| `cuadc_mission` | `ament_cmake` | 单个 C++ 状态机及其原有导航、跟踪、投放逻辑 |
| `cuadc_perception` | `ament_python` | 原视觉适配器、分析模块、地面预览和三个模型 |
| `cuadc_tools` | `ament_python` | 独立 GPS 航向标定、MAVLink 发送频率设置、CSV 遥测 |
| `cuadc_bringup` | `ament_python` | 全任务启动、原 YAML 参数和标定航向加载 |

参考项目含独立载荷、安全、飞控适配、自定义接口等包；原压缩包采用单节点内部实现。本版没有为对应这些目录而创建空包，也没有改变载荷控制的调用链。

## 桶视觉接口

默认话题为 `/perception/drop_buckets_body`，消息类型为 `geometry_msgs/msg/PoseArray`。字段沿用原包：

| 字段 | 含义 |
| --- | --- |
| `header.stamp` | 图像采集返回后的 ROS 时间戳，记录在深度对齐和推理之前 |
| `header.frame_id` | 默认 `fcu_body_frd` |
| `position.x/y/z` | 桶中心的机体 FRD 坐标，单位为米 |
| `orientation.x` | 桶直径，单位为米 |
| `orientation.y` | 检测置信度 |
| `orientation.z/w` | 桶口中心的机体 FRD X/Y 坐标，单位为米 |

这里的 `orientation` 承载自定义标量，不能作为姿态四元数解释。无有效目标时仍发布空数组，作为视觉心跳。

## 坐标系

飞控机体 FRD 的轴向为前、右、下；任务内部 FLU 为前、左、上。MAVROS 位置与设定点使用 ENU。场地航向以正北为 0°、顺时针增加，转换为 ENU 偏航角时采用 `yaw_enu = 90° - heading_deg`。

## 实际进程

正常 launch 创建 MAVROS、发送频率配置、遥测记录、桶视觉和任务节点。发送频率配置工具完成请求后退出；任务节点退出时触发 launch 关闭。相机由视觉代码直接读取，因此本版未启动额外的 RealSense ROS 图像节点。

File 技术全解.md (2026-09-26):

# 2026 赛季备赛技术选型记录

> 此文档用于记载 2026 赛季备赛流程中的技术选型、环境配置及相关方案变更。

---

## Ubuntu

2026 赛季开发环境统一采用：

- **Ubuntu 22.04 LTS**
- 本地开发与测试采用 **Windows + Ubuntu 双系统**

Ubuntu 22.04 作为本赛季主要 Linux 开发环境，用于 ROS 2、ArduPilot、Gazebo 以及无人机自主飞行相关代码的开发与验证。

---

## ROS

ROS 采用：

- **ROS 2 Humble Hawksbill**

ROS 2 Humble 与 Ubuntu 22.04 具有较好的兼容性，并且属于 ROS 2 的 LTS 版本，作为本赛季机器人通信、传感器数据处理以及自主飞行算法的主要软件框架。

---

## Gazebo

### 初始方案

最初计划采用：

- **Gazebo Classic 11.x.x**

主要用于：

- 本地自动飞行代码验证
- 无人机动力学仿真
- 传感器仿真
- ArduPilot SITL 联调

### 配置问题

Gazebo Classic 11.x.x 在 Ubuntu 22.04 上的配置过程并不理想，最终配置失败。

对于 Ubuntu 22.04：

- **Gazebo Fortress** 才是对应的 LTS 稳定版本
- 但 Fortress 与当前 ArduPilot 仿真方案的兼容性存在问题
- Gazebo Classic 11 的整体使用体验和后续支持情况也不理想

### 最终方案

因此最终决定采用：

- **Gazebo Harmonic**

Gazebo Harmonic 用于后续无人机仿真、自动飞行程序验证以及传感器仿真。

官方网站：

[Gazebo 官方网站](https://gazebosim.org/home)

### RGB-D 相机仿真

在调研过程中发现：

- Gazebo Classic 对 RGB-D 相机仿真的支持存在限制
- Gazebo Harmonic 对 RGB-D 相机及新一代传感器仿真支持更完善

相关官方对比：

[Gazebo Classic 与新版 Gazebo 功能对比](https://gazebosim.org/docs/harmonic/comparison/)

---

## ArduPilot

飞控固件采用：

- **ArduCopter**

主要使用 Mission Planner 中原生提供的 ArduCopter 系列飞控固件。

ArduPilot 负责无人机底层飞行控制，包括：

- 姿态控制
- 位置控制
- 高度控制
- 航点飞行
- 自动起降
- MAVLink 通信
- 外部控制接口

相关链接：

- [ArduPilot 官方文档](https://ardupilot.org/ardupilot/index.html)
- [Mission Planner GitHub](https://github.com/ArduPilot/MissionPlanner)

---

## Watt Toolkit

**Watt Toolkit** 用于改善部分 GitHub 资源的访问速度。

主要用途：

- GitHub 访问加速
- GitHub Release 下载加速
- 部分开发资源下载加速

在 Linux 开发环境配置以及 ROS、ArduPilot 等相关依赖下载过程中使用。

---

# 硬件选型

## 飞控

目前考虑和使用过的 CUAV 飞控包括：

### CUAV V5 Nano

早期使用的飞控平台之一。

---

### CUAV X7+ Pro

CUAV X7 系列飞控。

官方资料：

[CUAV X7+ Pro](https://www.cuav.net/x7-plus-pro/)

---

### CUAV 7-Nano

目前重点使用的飞控之一。

特点：

- 体积较小
- 适合无人机机载使用
- 支持 ArduPilot
- 接口资源较丰富
- 便于与 RTK、机载电脑、数传等设备连接

官方资料：

[CUAV 7-Nano](https://www.cuav.net/7-nano/)

---

### CUAV V6X V2

作为另一套飞控备选方案。

官方资料：

[CUAV V6X V2](https://www.cuav.net/v6x-v2/)

---

## RTK

RTK 初期选型：

- **CUAV C-RTK 2HP**

主要用于：

- 高精度定位
- 无人机定点飞行
- 自动航线飞行
- 提高位置控制精度

官方资料：

[CUAV C-RTK 2HP](https://www.cuav.net/c-rtk-2hp/)

后续根据航向稳定性需求，可进一步考虑：

- 双天线 RTK
- Moving Base
- GPS Heading
- RTK + 外置罗盘组合方案

---

## 机载电脑

目前考虑过的 Intel NUC 机载计算平台包括：

### Intel NUC 10

主要用于：

- ROS 2 节点运行
- 视觉算法
- 自主飞行算法
- MAVLink 通信
- 数据处理

---

### Intel NUC 13

作为性能更高的机载计算平台备选。

主要用于：

- 高计算量视觉算法
- 多传感器融合
- 自主规划
- ROS 2 系统
- 深度学习推理
- 飞控通信与任务控制

---

# 当前软件技术栈

目前 2026 赛季基础软件环境确定为：

| 模块 | 技术选型 |
| --- | --- |
| 操作系统 | Ubuntu 22.04 LTS |
| ROS | ROS 2 Humble |
| 仿真平台 | Gazebo Harmonic |
| 飞控固件 | ArduPilot / ArduCopter |
| 地面站 | Mission Planner |
| 飞控通信 | MAVLink |
| GitHub 加速 | Watt Toolkit |

---

# 当前主要硬件技术栈

| 模块 | 主要选型 |
| --- | --- |
| 飞控 | CUAV 7-Nano |
| 备选飞控 | CUAV X7+ Pro / CUAV V6X V2 / CUAV V5 Nano |
| RTK | CUAV C-RTK 2HP |
| 机载电脑 | Intel NUC 10 / Intel NUC 13 |

---

# 通讯链路

### 数传 微空 LR900-P
### 采用4G模块

# 算法汇总

> 说明：这里按我们项目历版状态机的**任务层、导航层、视觉层、投放层和安全层**归纳。  
> 其中“飞控底层算法”不是我们在状态机里重新实现的，而是状态机通过 MAVROS / ArduPilot 调用并依赖的能力。

---

## 1. 有限状态机（FSM）

整个自主任务采用 **Finite State Machine，有限状态机** 组织，将复杂任务拆成若干离散阶段，例如：

```text
等待飞控连接
→ 切换飞行模式
→ 解锁
→ 起飞
→ 航线飞行
→ 投放搜索
→ 视觉对准
→ 投放
→ 侦察
→ 返航/降落
→ 任务结束
```

核心思想是：**任何时刻只执行当前状态对应的任务，满足转移条件后进入下一状态。**

---

## 2. 条件触发与状态转移算法

每个状态都设置进入条件、完成条件和异常条件，例如：

- 飞控已连接才允许进入模式设置；
- GUIDED 模式确认后才能解锁；
- 解锁成功后才能起飞；
- 高度达到阈值后才进入航线任务；
- 目标稳定满足条件后才允许投放；
- 超时、目标丢失或传感器异常时进入恢复或返航逻辑。

本质上属于**基于事件和条件的离散决策算法**。

---

## 3. 非阻塞异步服务调用与重试

对模式切换、解锁、起飞等 MAVROS 服务采用异步调用：

```text
发送请求
→ 不阻塞主循环
→ 检查 future 是否返回
→ 判断成功/失败
→ 失败则再次尝试
```

这样可以避免一个服务请求卡住整个状态机。

典型应用：

- GUIDED 模式切换重试；
- ARM 解锁重试；
- 起飞命令确认；
- 降落命令触发。

---

## 4. 超时保护与 Watchdog

关键动作均设置超时，例如起飞长时间未达到目标高度时不无限等待。

基本形式：

```text
if 当前时间 - 状态开始时间 > 最大允许时间:
    执行降级策略 / 跳转恢复状态 / 返航
```

用于防止状态机“卡死”。

---

## 5. 起飞阶段 Setpoint 互斥算法

早期状态机中发现：ArduPilot 的 `takeoff` 命令与位置 setpoint 同时控制高度时可能互相冲突。

因此采用：

```text
起飞阶段：暂停发布位置 setpoint
达到目标高度：恢复 setpoint 发布
```

本质是**控制源互斥**，避免两个控制目标同时争夺飞行器。

---

# 二、导航与航线算法

## 6. 局部坐标系航点导航

状态机以局部位置坐标表示航点：

```text
P_i = (x_i, y_i, z_i)
```

按照航点顺序逐点发布目标位置，由飞控底层位置控制器完成跟踪。

---

## 7. 欧氏距离航点到达判定

二维航点距离采用：

```text
d = sqrt((x-x_target)^2 + (y-y_target)^2)
```

当：

```text
d < waypoint_tolerance
```

则认为进入航点容差范围。

---

## 8. 航点驻留 / 去抖判定

不是一进入航点半径就立即切换，而是要求连续保持一段时间：

```text
距离小于阈值
+ 持续时间大于阈值
→ 航点确认到达
```

作用是避免 GPS/定位噪声导致航点状态反复跳变。

---

## 9. 初始航向锁定算法

比赛任务中使用**起飞后的初始航向作为全任务参考航向**。

即记录：

```text
yaw_0 = 起飞阶段稳定后的航向
```

后续航线飞行、搜索和视觉对准尽量保持：

```text
yaw ≈ yaw_0
```

这样可以减少机体旋转对视觉坐标、相机投影和场地几何关系的影响。

---

## 10. 场地中轴线重建算法

为了不依赖绝对地图方向，我们使用两个现场参考点构造场地坐标系：

```text
P0 = 起飞点
P1 = 沿场地中轴线前进一定距离后的参考点
```

中轴线单位方向：

```text
e_forward = (P1 - P0) / |P1 - P0|
```

横向方向：

```text
e_lateral = (-e_forward.y, e_forward.x)
```

之后所有任务点均写成：

```text
P = P0 + s * e_forward + l * e_lateral
```

其中：

- `s`：沿场地纵向距离；
- `l`：相对中轴线横向偏移。

该算法可以让整套航线随现场摆放方向自动旋转。

---

## 11. 平行搜索航线生成算法

投放搜索采用多条与中轴线平行的搜索线。

例如两条航线可表示为：

```text
Line_1 = 中轴线 + lateral_offset
Line_2 = 中轴线 - lateral_offset
```

通过左右平移生成平行航线，实现对投放区域的覆盖搜索。

侦察区域可使用单条中心航线快速穿越，从而减少任务时间。

---

## 12. 顺序航点跟踪算法

航线由有序航点数组组成：

```text
W0 → W1 → W2 → ... → Wn
```

每次只追踪当前航点，确认到达后：

```text
waypoint_index++
```

直到当前航线完成。

---

# 三、视觉感知算法

## 13. 神经网络目标检测

视觉节点使用 ONNX 检测模型识别投放目标/任务目标。

典型输出：

```text
类别
置信度
目标框 bbox
目标中心像素 (u, v)
```

状态机不直接完成神经网络推理，而是消费视觉节点输出的检测结果。

---

## 14. 置信度阈值筛选

只保留：

```text
confidence >= threshold
```

的候选目标，过滤低可信检测结果。

---

## 15. NMS / 重复检测抑制

视觉检测模型通常通过 **Non-Maximum Suppression，非极大值抑制** 去除同一目标上的多个重复框，只保留最可信检测结果。

---

## 16. 目标锁定与数据关联

检测到多个候选目标时，不立即在不同目标之间跳转，而是优先维持当前目标锁定。

关联依据通常包括：

- 检测框中心距离；
- 上一帧目标位置；
- 类别一致性；
- 置信度；
- 是否位于允许搜索区域。

目的是提高连续跟踪稳定性。

---

## 17. 多帧稳定判定 / 时间滤波

单帧检测不能直接触发投放。

状态机要求目标在连续若干帧或一段时间内保持有效，例如：

```text
连续检测
+ 位置变化较小
+ 置信度满足要求
→ stable_target = true
```

用于过滤误检和偶发抖动。

---

## 18. 图像像素误差计算

目标中心：

```text
(u_t, v_t)
```

相机期望对准点：

```text
(u_0, v_0)
```

像素误差：

```text
ex = u_t - u_0
ey = v_t - v_0
```

该误差是视觉闭环控制的直接输入之一。

---

## 19. 针孔相机几何投影

利用相机内参和飞行高度，将像素误差转换为地面水平位移估计。

近似形式：

```text
X ≈ Z * (u-cx) / fx
Y ≈ Z * (v-cy) / fy
```

其中：

- `fx, fy`：相机焦距参数；
- `cx, cy`：主点；
- `Z`：相机到目标平面的距离。

---

## 20. 相机外参与机体系变换

相机坐标系与机体坐标系不完全重合，因此需要使用相机安装外参进行变换：

```text
P_body = R_bc * P_camera + t_bc
```

用于补偿相机安装角度和安装位置偏差。

---

## 21. 飞行姿态补偿

无人机飞行时存在 Roll、Pitch、Yaw，图像中的目标偏移不能直接等价为水平位移。

因此使用姿态旋转关系：

```text
P_world = R_wb(roll, pitch, yaw) * P_body
```

主要补偿：

- 横滚 Roll；
- 俯仰 Pitch；
- 偏航 Yaw；
- 相机安装姿态。

这样可将视觉测量统一到地面/任务坐标系中。

---

# 四、视觉闭环对准算法

## 22. 基于视觉误差的 P 型闭环控制

根据目标相对机体的水平误差生成速度或位置修正：

```text
vx_cmd = Kx * ex
vy_cmd = Ky * ey
```

或者根据地面坐标误差：

```text
vx_cmd = Kx * dx
vy_cmd = Ky * dy
```

属于典型的 **Visual Servoing（视觉伺服）**。

---

## 23. 死区算法

当误差已经很小时不继续频繁修正：

```text
if |e| < deadband:
    command = 0
```

作用：

- 减少目标附近抖动；
- 减少飞行器来回摆动；
- 提高投放稳定性。

---

## 24. 速度限幅算法

视觉控制指令限制在安全速度范围：

```text
v_cmd = clamp(v_cmd, -v_max, v_max)
```

防止检测误差突然增大时产生过激控制。

---

## 25. 分段速度 / 近远目标增益算法

距离目标较远时允许较快接近，进入目标附近后降低速度：

```text
误差大 → 快速移动
误差中 → 中速移动
误差小 → 慢速精调
```

属于简单的增益调度或分段比例控制。

---

# 五、投放算法

## 26. 相机—投放机构固定偏置补偿

相机光轴、机体中心和水瓶实际释放点通常不重合。

通过标定得到固定偏移：

```text
Δx_drop
Δy_drop
```

实际对准点不是图像中心，而是经过投放机构几何偏置修正后的目标点。

---

## 27. 投放触发多条件门控

不是“看到目标就投”，而是同时满足若干条件：

```text
目标有效
AND 目标连续稳定
AND 水平误差小于阈值
AND 飞行高度满足要求
AND 飞行速度足够小
AND 姿态处于允许范围
AND 检测数据未过期
AND 当前载荷尚未投放
```

全部成立后才进入 `DROP` 状态。

这属于**多条件安全门控算法**。

---

## 28. 投放稳定驻留算法

目标进入允许误差范围后，还需保持一段时间：

```text
误差满足条件持续 T 秒
→ 执行投放
```

避免飞机高速掠过目标时瞬间满足条件而误投。

---

## 29. 已投目标去重 / 排除算法

完成第一次投放后，需要避免再次锁定同一个目标。

基本思想：

```text
保存已投目标的位置
新检测目标与已投位置比较
距离过近 → 认为是同一目标 → 排除
```

用于提高第二个载荷投向不同目标的概率。

---

## 30. 舵机投放时序控制

投放机构不是单次变量赋值，而是一个小状态机：

```text
锁定位置
→ 打开舵机
→ 保持一定时间
→ 回到安全位置
→ 标记载荷已投放
```

避免重复触发和舵机动作不完整。

---

# 六、侦察识别算法

## 31. 目标类别识别

视觉模型识别危险化学品标识，并输出对应类别。

状态机记录识别结果，供比赛结束填写侦察结果使用。

---

## 32. 多帧投票 / 置信度累计

为了防止某一帧分类错误，可对同一侦察目标连续多帧结果进行统计：

```text
类别 A：n 次
类别 B：m 次
类别 C：k 次
```

选择稳定出现次数最多或累计置信度最高的类别作为最终结果。

---

## 33. 已识别目标去重

通过目标空间位置或检测框关联判断是否已经识别过该目标，避免同一标识被重复计数。

---

# 七、安全与容错算法

## 34. 数据新鲜度检查

视觉、定位、飞控状态等信息均带时间戳。

若：

```text
当前时间 - 数据时间戳 > 最大允许延迟
```

则该数据视为失效，不参与控制或投放判断。

---

## 35. 连接状态与飞行状态检查

持续检查：

- FCU 是否连接；
- 是否仍处于要求的飞行模式；
- 是否保持解锁；
- 定位是否有效；
- 高度是否合理；
- 视觉节点是否正常输出。

异常时停止继续推进任务。

---

## 36. 状态超时恢复算法

搜索目标、视觉对准、投放等状态都有最大允许时间。

超时后可采用：

```text
重新搜索
→ 切换下一条搜索航线
→ 放弃当前目标
→ 继续后续任务
→ 返航/降落
```

防止一个目标耗尽全部比赛时间。

---

## 37. 任务降级策略

任务优先级通常是：

```text
飞行安全 > 完成有效任务 > 追求更高精度
```

因此在局部任务失败时，不一定结束整个任务，而是根据剩余时间和系统状态继续后续流程。

---

## 38. 自动返航 / 自动降落逻辑

任务结束或异常达到返航条件后：

```text
离开任务区域
→ 返回起降点
→ 降低速度
→ LAND
→ 高度接近地面后结束状态机
```

返航状态还承担视觉任务失败后的最终安全兜底。

---

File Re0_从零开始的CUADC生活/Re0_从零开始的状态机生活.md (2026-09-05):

# CUADC C++：从零基础到完整任务状态机

## · C++17 / ROS 2 Humble / MAVROS

> **给谁读**：能使用电脑，但没有系统学习过C++的人；也适合会改代码、却不清楚引用、生命周期和异步语义的队员。
> **学习目标**：从一个可编译的main出发，逐步建立阅读和编写CUADC任务程序所需的语言、标准库与软件组织能力。
> **写作边界**：不是ISO C++全语言百科；重点覆盖基准工程实际使用的C++17知识及必要先修。原工程事实、语言背景、教学简化与改进分别说明。
> **安全边界**：前51章可离线学习；配套纯C++例程无硬件控制接口。ROS练习使用隔离教学话题和加法服务，不提供真实起飞/投放入口。
> **日期**：2026-09-05。原教程与原v11文件均保留，本书不覆盖它们。

## 先看这一页：怎样使用这份长教程

本书中标为**完整例程**的代码都有对应文件、构建命令和实际捕获输出；标为**语法片段/源码摘录**的代码用于局部讲解，不承诺单独复制就能编译。故意错误的例子有明确标记，不能当作可运行参考。

练习顺序固定为：读需求 → 手算/预测 → 编译运行 → 比较结果 → 做一处变更 → 给变更补测试。暂时不会的前置概念应回到对应章节，而不是继续背更长的一行。

| 你目前的情况 | 从哪里开始 | 暂时不要做什么 |
|---|---|---|
| 没学过C++ | 第1—12章、例程01—06 | 不接飞控、不看完整节点 |
| 会if/for，但引用和类薄弱 | 第13—28章 | 不先写多线程或复杂模板框架 |
| 会基础C++，读不懂ROS长类型 | 第29—44章，再到第52章 | 不把API调用当语言关键字 |
| 能写ROS节点，想维护任务代码 | 第45—64章及源码函数索引 | 不把教学简化程序直接部署真机 |

**配套目录提示**：下面编译命令假定当前工作目录是ZIP解压后、含根CMakeLists.txt的目录；单独复制某个例程时可改用相应本地文件路径。

## 可点击目录

**第一篇：先让一个小程序真正运行起来**

- [第1章：先分清我们在学什么，再决定从哪里开始](#ch01)
- [第2章：文件、终端、编辑器、编译器，分别是什么](#ch02)
- [第3章：第一个程序，逐个符号讲清楚](#ch03)
- [第4章：程序为什么会失败——预处理、编译、链接与运行](#ch04)

**第二篇：用数据和控制流程描述任务**

- [第5章：变量、声明、初始化、赋值，不是一回事](#ch05)
- [第6章：类型、取值范围、`size_t` 与有符号/无符号](#ch06)
- [第7章：整数除法、浮点误差、字面量与单位转换](#ch07)
- [第8章：输入、输出、字符串，先从可靠读取一个数开始](#ch08)
- [第9章：运算符与表达式，把每个条件读成一句话](#ch09)
- [第10章：`if`、`else` 与提前返回——把错误入口挡在外面](#ch10)
- [第11章：循环不是“程序卡住”，关键在于每次推进了什么](#ch11)
- [第12章：第一次阶段实践——写一个离线任务条件检查器](#ch12)

**第三篇：函数、引用、指针与数据结构**

- [第13章：函数从零——谁调用谁，值从哪里来，执行到哪里回去](#ch13)
- [第14章：函数声明、定义、重载、默认参数与接口设计](#ch14)
- [第15章：引用与参数传递——把 `const T&` 讲透](#ch15)
- [第16章：指针、地址、解引用与空值——不跳过任何一层](#ch16)
- [第17章：作用域、生命周期、`const`、`constexpr`、`static` 与命名空间](#ch17)
- [第18章：数组、字符串、`char** argv` 与字符串视图](#ch18)
- [第19章：`struct` 与 `enum class`——第一次建立任务的数据语言](#ch19)
- [第20章：第二次阶段实践——离线航点检查器](#ch20)

**第四篇：对象、类、资源与所有权**

- [第21章：`class`、对象、成员函数与 `this`](#ch21)
- [第22章：构造函数与初始化列表——冒号后面到底发生什么](#ch22)
- [第23章：析构、RAII、异常、`noexcept`——资源怎样可靠收尾](#ch23)
- [第24章：复制、移动、左值右值与 Rule of Zero](#ch24)
- [第25章：`unique_ptr`——一个资源只有一个拥有者](#ch25)
- [第26章：`shared_ptr`、`weak_ptr` 与 ROS 的 `SharedPtr`](#ch26)
- [第27章：继承、虚函数、`override`、`final` 与组合](#ch27)
- [第28章：函数指针、成员函数指针、`std::function` 和 `std::bind`](#ch28)

**第五篇：读懂现代 C++ 的类型、容器和算法**

- [第29章：`auto`、类型别名、`decltype` 与长类型拆解](#ch29)
- [第30章：Lambda 逐个符号拆解——捕获、参数、返回、生命周期](#ch30)
- [第31章：模板从最简单函数开始——类型参数不是运行参数](#ch31)
- [第32章：`std::array` 与 `std::vector`——长度、容量、元素和生命周期](#ch32)
- [第33章：`deque`、队列、历史窗口与移动后删除](#ch33)
- [第34章：`optional`、`pair`、`tuple`、`variant`——不要用一个零代表所有未知](#ch34)
- [第35章：迭代器与半开区间——理解 `begin()`、`end()` 和失效](#ch35)
- [第36章：查找和判定算法——从手写循环到 `find_if`、`all_of`、`lower_bound`](#ch36)
- [第37章：排序、比较器、删除与归约——不要把容器算法当黑盒](#ch37)
- [第38章：map、set、哈希容器与复杂度——什么时候不用 vector](#ch38)

**第六篇：把语言知识变成可验证的工程代码**

- [第39章：数学工具、有限值、范围检查与“安全默认值”的边界](#ch39)
- [第40章：文件、流、解析与日志——读到字符串不等于读到合法数值](#ch40)
- [第41章：从一个 `.cpp` 到多文件工程——头文件、ODR 与 CMake](#ch41)
- [第42章：调试、测试、警告与 Sanitizer——怎样证明修改没有破坏旧行为](#ch42)
- [第43章：`chrono` 从时间单位讲到时间点——为什么不能拿所有时间互相减](#ch43)
- [第44章：异步从零——`promise`、`future`、线程、锁与 ROS 回调](#ch44)

**第七篇：把已经学会的 C++，组合成可测试的任务零件**

- [第45章：状态机不是 `switch` 的别名，而是跨调用保存进度](#ch45)
- [第46章：连续稳定门——把布尔值、时间和 `optional` 串起来](#ch46)
- [第47章：从 `Point3` 到投放口几何，先理解“数据代表什么”](#ch47)
- [第48章：轨迹函数，按公式一步一步实现](#ch48)
- [第49章：导航历史与时间插值，把容器和算法真正用起来](#ch49)
- [第50章：跟踪与目标冻结——从“一次测量”变成“任务对象”](#ch50)
- [第51章：阶段大实践——完整但不接飞机的任务状态机](#ch51)

**第八篇：现在才进入 ROS 2——把框架调用读回普通 C++**

- [第52章：一个 ROS 节点，究竟何时构造、何时运行](#ch52)
- [第53章：消息、发布和订阅的类型，逐层解开](#ch53)
- [第54章：参数不是全局变量——声明、加载、验证和生效](#ch54)
- [第55章：执行器、回调组和对象寿命，为什么程序会卡住](#ch55)
- [第56章：ROS异步服务，完整示范pending请求的生命周期](#ch56)
- [第57章：MAVROS只是换了消息与服务类型，不能省掉业务判断](#ch57)
- [第58章：阅读4345行v11的正确顺序，不是从第1行一路硬啃](#ch58)

**第九篇：带着语言知识逐段阅读正式源码**

- [第59章：源码精读一——移动队列元素、查找轨迹与忽略返回值](#ch59)
- [第60章：源码精读二——粗对准、细对准与RELEASE门禁](#ch60)
- [第61章：失败处理、返航与原版侦察，别把日志当物理事实](#ch61)
- [第62章：重构时先保留行为，再谈模块漂亮](#ch62)
- [第63章：常见错误字典——从症状倒查C++知识点](#ch63)
- [第64章：学习安排与总验收——不是读完多少行，而是能独立解释多少行为](#ch64)
- [附录A：同一个符号为什么有不同意思](#appendix-a)
- [附录B：标准库与ROS常用接口速查](#appendix-b)
- [附录C：与原版教程相比，哪些地方明确澄清或改变了](#appendix-c)
- [附录D：配套纯C++核心模块完整文件](#appendix-d)
- [附录E：单元测试不是注释——完整测试文件](#appendix-e)
- [附录F：故意写错，再读懂编译器](#appendix-f)
- [附录G：实践索引与知识点覆盖](#appendix-g)
- [附录H：基准v11函数与实际行号索引](#appendix-h)
- [附录I：如何读“看起来最复杂的一行”](#appendix-i)
- [附录J：来源、版本与验证边界](#appendix-j)

---

# 第一篇：先让一个小程序真正运行起来

# 第 1 章：先分清我们在学什么，再决定从哪里开始

## 1.1 目标不是背代码，而是建立四种能力

学习这份教材的终点，是能够从空文件写出一个可以解释、可以测试、可以维护的任务程序。看到 `const Point3&` 时，你应当知道它怎样传递数据；看到 `[this]` 时，应当知道谁必须继续活着；看到 `future.wait_for(...)` 时，应当知道程序到底有没有在等待；看到 `State::RELEASE` 时，应当能说明它为何进入、何时离开，以及异常时如何退出。

这里有四个不同层次，不能同时混学：

| 层次 | 要解决的问题 | 例子 |
|---|---|---|
| C++ 语言 | 怎样表达数据、操作与生命周期 | 变量、函数、引用、类、模板 |
| C++ 标准库 | 怎样使用通用工具 | `vector`、`optional`、`chrono`、`future` |
| ROS 2 框架 | 多个程序怎样交换消息和调度回调 | Node、Topic、Timer、Service |
| CUADC 业务 | 怎样搜索、对准、投放、侦察和退出 | 状态机、目标记忆、稳定门禁 |

原教程较早把四层写在一起。例如，刚接触函数的读者就要同时面对 `Point3`、`const`、引用和 `std::hypot`。本版先把每一种机制单独做成小实验，之后再组合。**前 44 章的主要任务是学习 C++，不是配置飞机。**

## 1.2 只需要一条主线

```text
认识文件和编译器
→ 变量、表达式、分支、循环
→ 函数、引用、指针、作用域
→ 结构体、类、构造、析构、所有权
→ 可调用对象、Lambda、模板、容器、算法
→ 多文件工程、测试、时间、异步
→ 纯 C++ 任务组件与模拟状态机
→ ROS 2 外壳与 v11 源码阅读
```

第一次学习，不要从最后的 ROS 完整类开始向前猜。每篇结束做一个能够运行的程序，再进入下一篇。最后的函数速查和源码索引用于复习，不是初学顺序。

## 1.3 这份教材中的三种材料

**已有材料**是你上传的旧 C++ 教程，以及 `cuadc_full_mission_node_3_v11(1).cpp`。涉及实际函数行为时，以这份上传源码为依据，不把此前讨论的 O4、高速转场等设想当成既有代码。

**教学补充**是本版新增的语言说明、内存示意、标准库解释、练习和重构方法。它们不是从原代码中“发现”的新功能。

**教学改写**是为了演示某个概念而重新写的小程序。它可以比 v11 更简单，也可能有额外的输入检查；凡行为不同之处会明确说明。它不能替代经过验证的比赛节点。

## 1.4 什么是“会了”

“读的时候觉得懂”不等于“能写”。每一阶段至少完成三件事：不看答案复写一个小程序；修改一个输入并预测结果；故意破坏一个条件，解释错误发生在哪一层。能解释失败，比只跑通一次更有价值。

整个配套工程默认只操作本地内存和教学文件。ROS 练习使用 `/cpp_tutorial/...` 命名空间，不提供真实 MAVROS 解锁、起飞或舵机发送程序。**不要为了试例程而把这些话题重映射到真机控制话题。**

**材料依据**：旧教程 [B0]、上传 v11 [B1]。语言范围采用 C++17；后续标准功能会标明不属于本书默认编译环境。

# 第 2 章：文件、终端、编辑器、编译器，分别是什么

## 2.1 一个 `.cpp` 文件只是一份文本

文件扩展名 `.cpp` 告诉人和工具“这里通常放 C++ 源代码”。它不是可执行程序。把文件重命名成 `fly` 并不会让它变成程序，给源文件增加执行权限也不会替代编译。

编辑器负责写文本；编译器负责检查 C++ 规则并产生机器代码；终端负责把你输入的命令交给操作系统。VS Code 是编辑器，`g++` 是编译器，Bash 是一种命令解释器。一个工具可以调用另一个工具，但它们不是同一件事。

## 2.2 先掌握最少的目录操作

以下是终端命令，不要写进 `.cpp` 文件：

```bash
mkdir -p ~/cuadc_cpp_basics
cd ~/cuadc_cpp_basics
pwd
ls
```

`mkdir -p` 创建目录；`cd` 改变当前工作目录；`pwd` 显示当前目录；`ls` 查看文件。`~` 表示当前用户的主目录。你在终端运行 `./hello` 时，`./` 表示从当前目录找文件，不是 C++ 语法。

文件名带空格或括号时应加引号：

```bash
wc -l 'cuadc_full_mission_node_3_v11(1).cpp'
```

不要把复制过程中附带的行号、`$` 提示符、Markdown 的三个反引号一起粘进文件。文件应使用纯文本、UTF-8 编码，扩展名不要误存成 `.cpp.txt`。

## 2.3 准备编译工具

Ubuntu 的教学环境可以通过包管理器安装构建工具。下面只安装本地开发工具，不刷写或配置飞控：

```bash
sudo apt update
sudo apt install build-essential cmake gdb python3
g++ --version
cmake --version
```

`sudo` 是以管理员权限执行系统操作，不需要用它运行你的普通 C++ 练习。安装命令属于环境准备，源码语义以 `-std=c++17` 为准。其他系统也可以学习同一套 C++，只是工具安装和可执行文件形式不同。

## 2.4 最值得记住的一条编译命令

```bash
g++ -std=c++17 -Wall -Wextra -Wpedantic -g hello.cpp -o hello
./hello
```

| 部分 | 意义 |
|---|---|
| `g++` | 调用 C++ 编译驱动程序 |
| `-std=c++17` | 使用 C++17 语言模式，不依赖编译器默认版本 |
| `-Wall -Wextra -Wpedantic` | 打开常用诊断；不表示发现所有可能错误 |
| `-g` | 生成调试信息，供调试器使用 |
| `hello.cpp` | 输入源文件 |
| `-o hello` | 输出程序命名为 `hello` |
| `./hello` | 执行编译得到的程序 |

**编译成功后再运行。** 更稳妥的写法是用 `&&` 连接：

```bash
g++ -std=c++17 -Wall -Wextra -Wpedantic hello.cpp -o hello && ./hello
```

这是 Shell 的条件执行，不是 C++ 的 `&&` 表达式。如果新版本编译失败，而目录里保留着上一次的 `hello`，直接运行可能误以为新代码生效。

**小练习**：在不同目录运行 `./hello` 会怎样？答案：操作系统在不同的当前目录查找，可能提示文件不存在；这与 C++ 语法没有关系。

参考：[R01]、[R02]。

# 第 3 章：第一个程序，逐个符号讲清楚

**完整例程 01：`examples/01_hello.cpp`**

```cpp
#include <iostream>

int main()
{
    std::cout << "Hello, CUADC!\n";
    return 0;
}
```

**编译与运行**（在配套工程根目录执行；只复制单文件时须相应调整路径）：

```bash
mkdir -p build
g++ -std=c++17 -Wall -Wextra -Wpedantic -g -pthread examples/01_hello.cpp -o build/ex_01_hello && \
  ./build/ex_01_hello
```

**本次运行捕获的标准输出**：

```text
Hello, CUADC!
```

## 3.1 `#include <iostream>`

`#include` 是预处理指令，作用是让这个翻译单元能够使用指定头文件提供的声明及相关定义。这里的 `iostream` 提供标准输入输出流相关接口。

尖括号不是“小于、大于”；在这条预处理指令里它们包围头文件名。后面写自己的头文件通常使用双引号，例如 `#include "geometry.hpp"`。尖括号和双引号的搜索细节由工具链配置决定，初学时理解为“标准或外部头文件”和“本工程头文件”即可。

`#include` 行后不要随手加 `;`。头文件提供的是编译时需要的信息；链接库的问题在第 4、41 章另讲。

## 3.2 `int main()`

`main` 是普通宿主环境下程序的入口函数名。`int` 表示函数返回整数；`()` 表示这里没有显式列出的参数；紧随其后的 `{...}` 是函数体。操作系统启动程序所需的运行库初始化仍然存在，不应把 `main` 理解成机器执行的第一条指令。

此时只需把 `main` 当成“我的程序从这里开始执行”。不要写 `void main()`。以后 ROS 版本的 `main(int argc, char** argv)` 只是多了命令行参数，并没有换一种语言。

## 3.3 `std::cout << "Hello, CUADC!\n";`

`std` 是标准库使用的命名空间名称。`::` 是作用域解析符，所以 `std::cout` 表示“标准库命名空间中的 cout”。`cout` 是标准输出流对象。

这里的 `<<` 是流插入运算，意为把右侧内容写入左侧流。它也可以连续使用：

```cpp
// 放在 main 函数体内的语法片段。
std::cout << "height=" << 1.3 << " m\n";
```

这不是把三个东西做二进制左移。C++ 允许同一运算符根据操作数类型表示不同操作，后面称为运算符重载。

双引号包围的是字符串字面量。`\n` 表示换行字符，不是两次输出反斜杠和字母 n。常见转义只需先记 `\n`、`\t`、`\\`、`\"`。中文文本可放在字符串或注释中，但程序标识符建议使用稳定、清楚的英文名。

## 3.4 `return 0;` 和分号

`return 0;` 结束 `main`，向调用环境报告成功状态。非零退出码通常用于报告失败，但每个具体数字的含义由程序约定。返回值不是“让飞机高度变成零”，也不是打印零。

分号结束一条语句。花括号组织代码块。缩进有助于人阅读，但一般不改变 C++ 语义。以下写法虽然难看，表达同样的程序：

```cpp
// 不推荐的排版示例。
int main(){return 0;}
```

类、结构体和枚举定义结束需要 `};`，普通函数定义结束通常只写 `}`。不要机械地给所有右花括号加分号。

## 3.5 注释不是程序命令

```cpp
// 单行注释：到行末结束。
/* 多行注释：
   可以跨行，但不能按普通方式嵌套。 */
```

注释可以过时，所以阅读实际工程时，必须检查注释与执行语句是否一致。比如“10 Hz”的旧注释不一定等于定时器真实周期。

**练习**：把输出分成两行，分别写 `CUADC` 和 `offline exercise`。再删掉一句的分号，观察编译错误指向哪里，然后恢复。错误信息有时在下一行暴露，但根因在前一行。

参考：C++17 `[basic.start.main]`、`[lex.comment]`、`[iostream.objects]`，见 [R03]。

# 第 4 章：程序为什么会失败——预处理、编译、链接与运行

## 4.1 从文本到进程的四步

```text
.cpp 和头文件
    ↓ 预处理：展开 include、条件编译等
翻译单元
    ↓ 编译与汇编：检查语法、类型，产生目标代码
.o 目标文件
    ↓ 链接：把各目标文件和库中需要的定义连接起来
可执行文件
    ↓ 运行
进程及其内存、文件、线程等资源
```

`g++ hello.cpp -o hello` 通常替你串起了中间步骤，所以你不一定看到 `.o`。需要观察时可以分开执行：

```bash
g++ -std=c++17 -E hello.cpp -o hello.ii
g++ -std=c++17 -c hello.cpp -o hello.o
g++ hello.o -o hello
```

`-E` 只做预处理，输出可能很长；`-c` 产生目标文件而不进行最终链接。

## 4.2 四种错误，不要混着查

| 现象 | 所在层 | 优先检查 |
|---|---|---|
| `iostream: No such file` 或找不到项目头文件 | 预处理/环境 | 工具链是否正确、include 路径 |
| `expected ';'`、类型不匹配 | 编译 | 当前行与前一行、声明、参数类型 |
| `undefined reference to ...` | 链接 | 有没有函数定义、是否加入相应 `.cpp` 或库 |
| 程序启动后崩溃、结果错误、一直等待 | 运行 | 生命周期、边界、输入数据、状态条件 |

“没有报编译错”只说明满足了编译器能检查的规则。访问已销毁对象、读数组之外的内存、数据竞争，都可能成功编译。

## 4.3 什么是未定义行为

未定义行为不是“系统默认返回一个随机值”，而是 C++ 标准不对该执行结果提出要求。你不能据一次运行正常推断下次也正常。初学阶段最常见的是未初始化标量读取、数组越界、悬空引用解引用、某些整数溢出，以及多线程中的未同步读写。

不要用“我这台电脑能跑”作为反驳。后面会用警告、测试、调试器和 Sanitizer 帮助发现这些问题，但没有任何单一工具能证明无人机任务安全。

## 4.4 一个重要习惯：每次只增加一个难点

先让 `hello.cpp` 成功，再加变量；变量成功再加分支。出现 200 行模板错误时，先看**第一条属于你自己代码的错误位置**，不要从最后一行开始乱改。

**本篇验收**：能区分源码和程序；能从终端编译；能解释 `#include`、`main`、`std::cout`、分号和返回码；能把失败归到环境、编译、链接或运行之一。

参考：[R01]、C++17 `[lex.phases]`、`[intro.execution]`，见 [R03]。

# 第二篇：用数据和控制流程描述任务

# 第 5 章：变量、声明、初始化、赋值，不是一回事

## 5.1 一个变量最少包含哪些信息

```cpp
// 函数体内的语法片段。
double height_m = 1.3;
```

`double` 是类型，告诉编译器这是浮点数；`height_m` 是名字；`1.3` 是初始值。声明告诉编译器名字及其类型；这里同时是定义，因为它创建了对象；初始化是对象创建时确定初始状态。

之后写：

```cpp
height_m = 1.7;
```

这是赋值：对象已经存在，改变它保存的值。等号在这里不表示数学上的永久相等关系。`height_m = height_m + 0.4;` 是先计算右侧，再把结果交给左侧。

## 5.2 三种常见初始化写法

```cpp
int count = 2;       // 复制初始化，不等于一定发生一次额外复制。
int other(2);        // 直接初始化。
int third{2};        // 列表初始化。
double height{};    // 对这个 double，初始化为 0.0。
```

初学时普通数值可以使用 `=`；定义聚合数据常用 `{}`。列表初始化还会拒绝某些窄化转换，例如 `int n{1.3};` 不能用来悄悄丢弃小数。

不要把所有花括号都叫“代码块”。`if (...) { ... }` 的花括号包围语句；`Point3{1,2,3}` 的花括号包围初始化数据。看它所在的位置才能判断用途。

## 5.3 未初始化不代表零

```cpp
// 错误示例，不要运行。
int count;
// std::cout << count; // 对该局部 int 的未初始化读取没有可依赖的结果。
```

不同存储期和不同类型有不同初始化规则。最实用的习惯是：**在定义时就给普通局部数值一个明确初值。** 不要依赖调试器恰好显示的零。

同时，零并不总是合法的“未知状态”。高度为零可以是地面位置，不能自动表示“没有高度”。后面用 `optional` 单独表达“没有值”。
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

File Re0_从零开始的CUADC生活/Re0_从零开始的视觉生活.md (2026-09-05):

# CUADC 视觉：从零到投放定位与 O4 侦察

**面向多旋翼无人机侦察与救援的完整学习教程**  
配套方向：Python / NumPy / OpenCV / RealSense D435i / ROS 2 / C++任务状态机 / DJI O4。  
版本：教学版1.0 · 2026-09-05

> 视觉不是“识别出一个框就结束”。本教程从新人能独立运行的小程序开始，逐步建立“图像 → 几何 → 时间 → 实体 → 任务证据”的完整链路。

## 这份教程与前两份有什么不同

C++教程教你表达程序逻辑；ROS教程教你组织节点与通信；这一份教你获得**可测量、可解释、可拒绝错误的视觉观测**，再把它交给任务状态机。

正文68章、7个附录。完整实践文件嵌入Markdown，同时提供独立代码包，便于不逐段复制地运行。数学推导与代码按章节逐步出现，末尾提供函数表、源码导航、术语、测试和官方资料入口。

## 材料边界

**已确认源码**：你上传的v11 C++状态机；**已确认规则**：上传的Ver20260330规则文件；**用户说明**：O4用于侦察；**新写内容**：本教程的视觉算法实现与练习。

没有实际视觉Python节点、真实模型权重和真实标定文件，因此不会把教学实现写成你们已经部署的算法。O4单线高速侦察和非任务区12m/s仍按“讨论方案、待验证”处理，不混入v11现状。

技术教学引用官方资料；源码事实标[P1]、规则标[P2]、用户信息标[U1]。其他示例、计算与测试均说明假设，来源索引见附录G。

## 三条学习路线

| 读者 | 建议先读 | 第一阶段交付 |
|---|---|---|
| 完全零基础 | 1～10、15、23～25、附录A/C | 能读图、找合成桶、解释像素与深度 |
| 已会YOLO但不会控制接口 | 12～22、32～50 | 有坐标、时间、质量与拒绝原因的ROS观测 |
| 负责比赛集成/侦察 | 2、39、43、47～58、59～66 | 实际链路、可读覆盖、参数边界与验证报告 |

每完成一个阶段，先解释输入、输出、单位、坐标、时间和失效情况，再增加功能。不要跳过合成与台架验收，直接把教学目标发给实机状态机。
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

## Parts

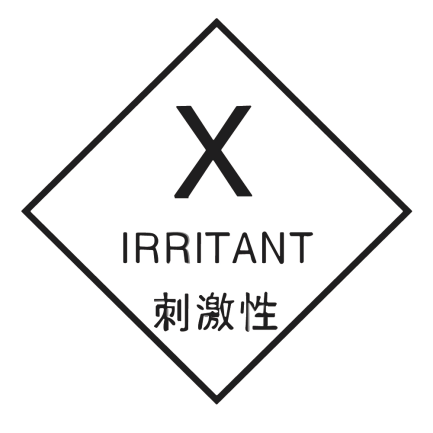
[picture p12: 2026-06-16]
sim/cuadc_hazard_recognition_sim-v0.2.0/models/hazard_marker/materials/textures/irritant.png

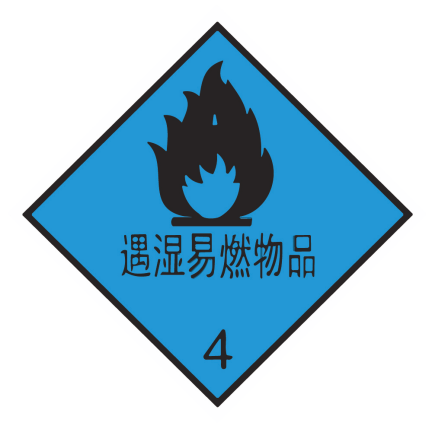
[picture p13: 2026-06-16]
sim/cuadc_sim/models/hazard_marker/materials/textures/dangerous_when_wet.png

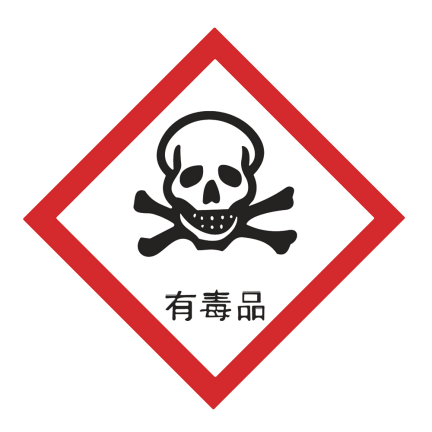
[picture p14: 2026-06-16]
sim/cuadc_hazard_recognition_sim-v0.2.0/models/hazard_marker/materials/textures/toxic.png

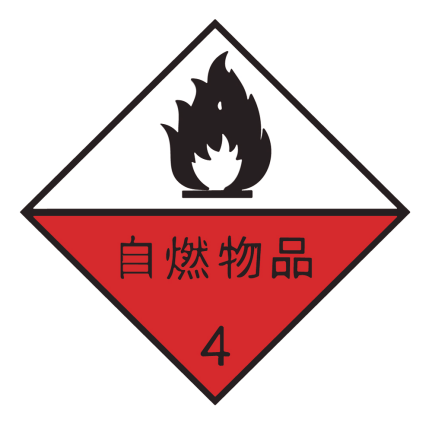
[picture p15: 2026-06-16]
sim/cuadc_sim/models/hazard_marker/materials/textures/spontaneously_combustible.png

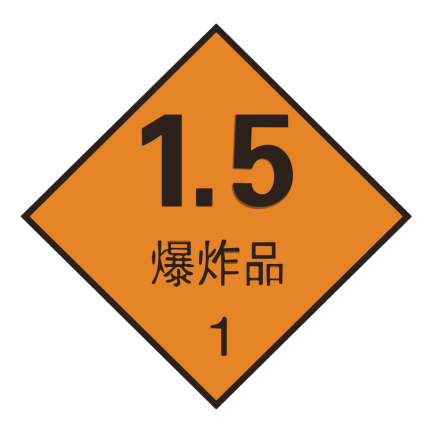
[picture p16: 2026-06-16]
sim/cuadc_hazard_recognition_sim-v0.2.0/models/hazard_marker/materials/textures/explosive.png

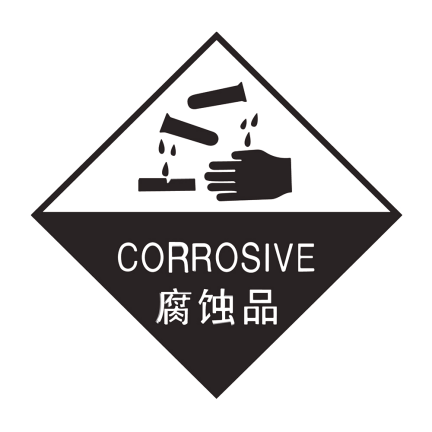
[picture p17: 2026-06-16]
sim/cuadc_sim/models/hazard_marker/materials/textures/corrosive.png

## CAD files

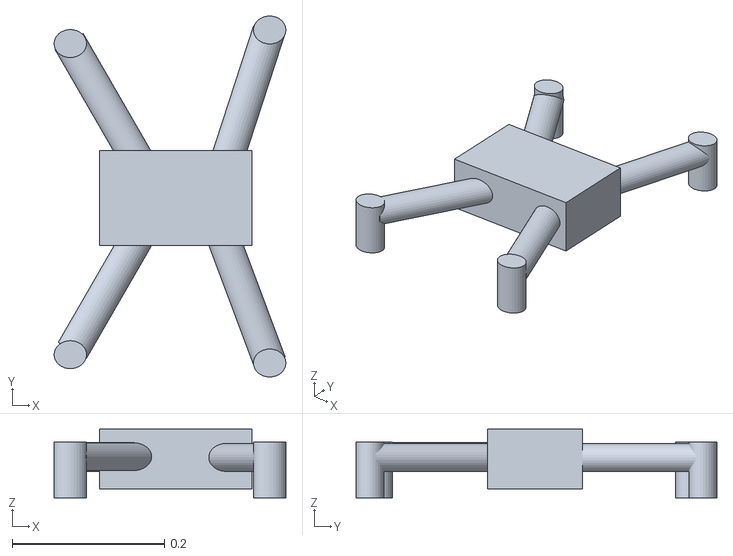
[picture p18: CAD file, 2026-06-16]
sim/cuadc_hazard_recognition_sim-v0.2.0/models/iris_d435i_airframe/meshes/iris_collision.stl
0.304 x 0.473 x 0.0899

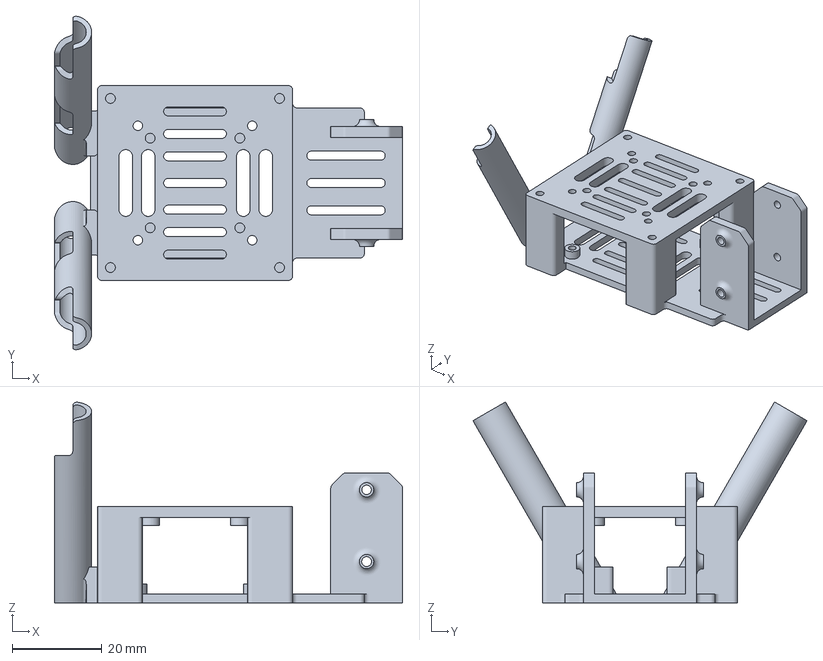
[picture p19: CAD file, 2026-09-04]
结构/DJI O4支架/04pdizuo.3mf
77.6 x 74.4 x 44.7 mm

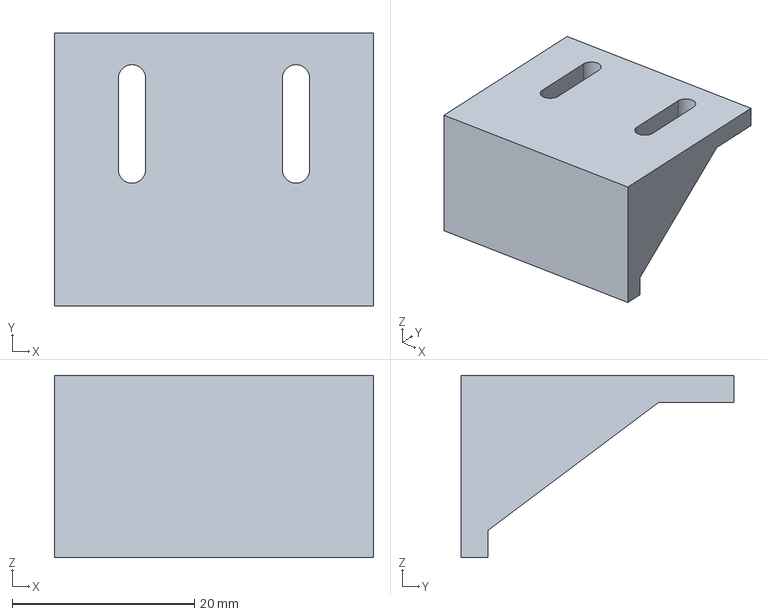
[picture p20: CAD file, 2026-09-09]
结构/图传打印件/Part1.stp
35.0 x 30.0 x 20.0 mm

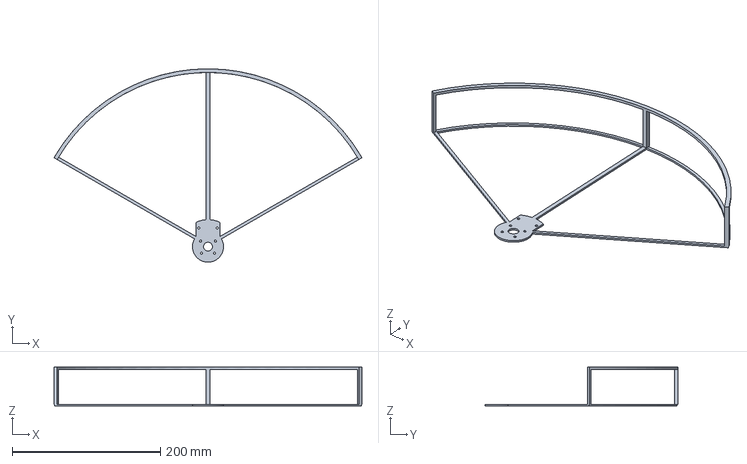
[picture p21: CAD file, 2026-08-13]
结构/桨保2.0/prop_guard.stp
415.7 x 261.0 x 52.0 mm

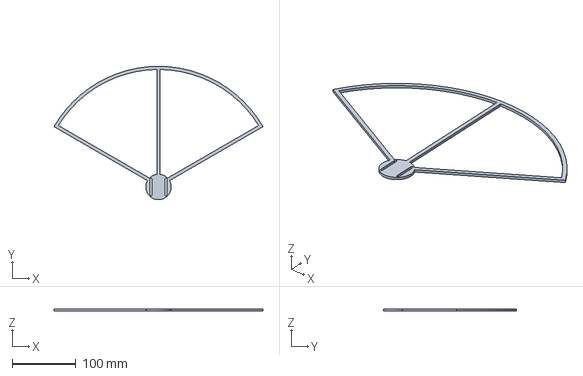
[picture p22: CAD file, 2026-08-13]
结构/桨保3.0/Part1.stp
329.1 x 210.0 x 3.00 mm

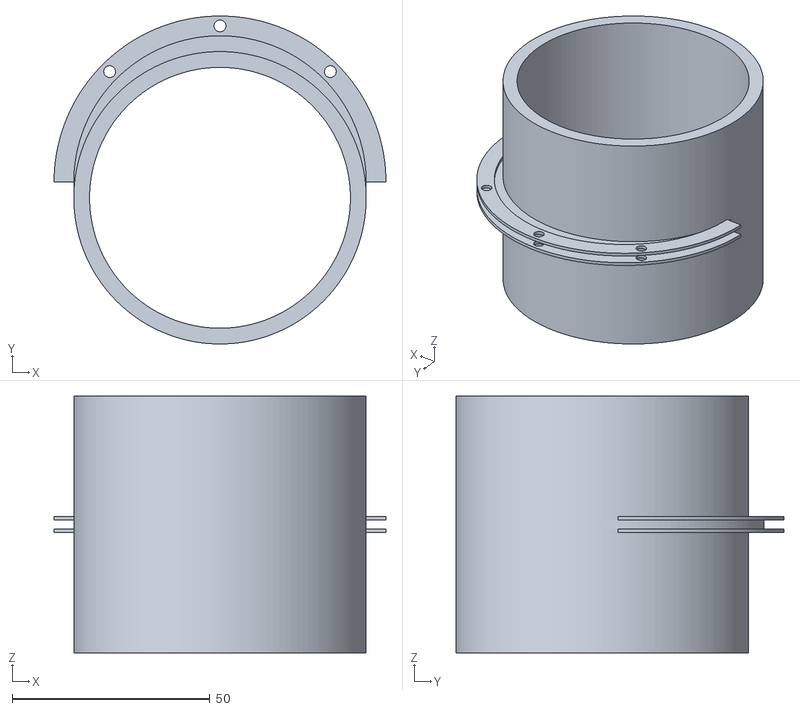
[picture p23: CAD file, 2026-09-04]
结构/限位2/Part1.stl
84.0 x 83.0 x 65.0

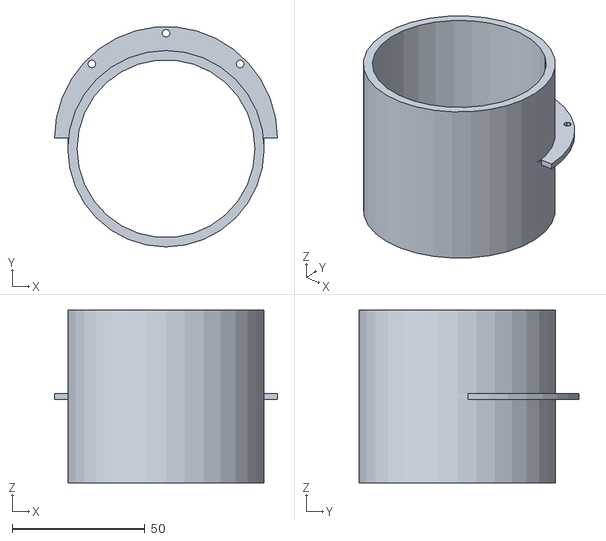
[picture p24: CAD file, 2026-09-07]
结构/限位3/1.stl
84.0 x 82.8 x 65.0

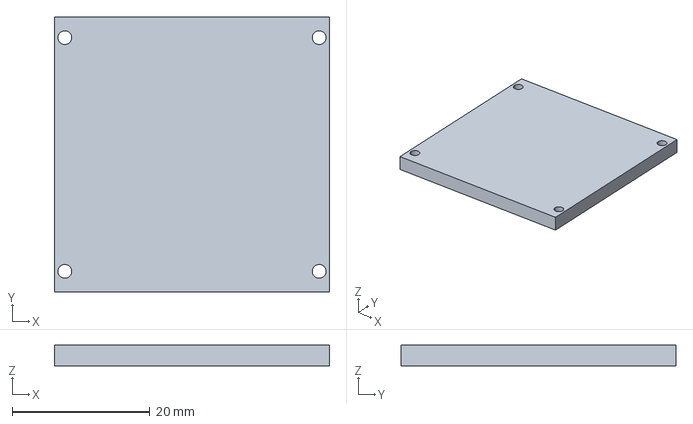
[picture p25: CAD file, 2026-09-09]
结构/图传打印件/2.stp
40.0 x 40.0 x 3.00 mm

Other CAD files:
结构/ZD550/Frame ZD550.CATProduct
结构/ZD550/Frame ZD550/A_iioa_ _a__e.CATPart
结构/ZD550/Frame ZD550/Aa_oi__ iea_oeia.CATPart
结构/ZD550/Frame ZD550/Aaeea I3-6H AI_O 5927-70.CATPart
结构/ZD550/Frame ZD550/Aaeea I3-6H.LF AI_O _ 50273-92.CATPart
结构/ZD550/Frame ZD550/Aeeiiue aeio.CATPart
结构/ZD550/Frame ZD550/Aeeiiue aeio_1.CATPart
结构/ZD550/Frame ZD550/Aeeoioe_oi_ia_ ieiuaaea.CATPart
结构/ZD550/Frame ZD550/Aeio I3x6 AI_O 28963-91.CATPart
结构/ZD550/Frame ZD550/Aeio _ oeeeia_e_a_eie aieiaeie e _a_oea_aiiui oaeoaeaieai iia ee__ AI_O _ E_I 4762 - I3 x 16.CATPart
结构/ZD550/Frame ZD550/Aeio _ oeeeia_e_a_eie aieiaeie e _a_oea_aiiui oaeoaeaieai iia ee__ AI_O _ E_I 4762 - I3 x 25.CATPart
结构/ZD550/Frame ZD550/Aeio _ oeeeia_e_a_eie aieiaeie e _a_oea_aiiui oaeoaeaieai iia ee__ AI_O _ E_I 4762 - I3 x 8.CATPart
结构/ZD550/Frame ZD550/Ca_ei.CATPart
结构/ZD550/Frame ZD550/E_a_oiaeia _a__e.CATPart
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

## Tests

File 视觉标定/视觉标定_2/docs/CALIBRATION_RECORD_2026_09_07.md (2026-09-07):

# 标定记录 2026-09-07

当前采用版本：

```text
P1 / SERVO9  FLU = [+0.0260, -0.0650, -0.3200]
P2 / SERVO10 FLU = [+0.0109, +0.0720, -0.3200]
```

相机：

```text
camera_offset_body_m = [0,0,-0.35]
camera_xy_calib_bias_m = [+0.047805,-0.014577]
R optical->FLU =
[-0.971358, +0.237622, 0
 +0.237622, +0.971358, 0
  0,         0,       -1]
```

正式投放高度保持 1.3 m。

标定演进摘要：

1. 先在较低静态高度用 P1/P2 两点估计相机平面 yaw + XY 偏移；
2. 到 1.3 m 正式工作高度复核；
3. P1 在当前相机外参下已较准；
4. P2 采用单独机械投放口修正，避免为了 P2 破坏 P1 已正确的全局相机外参；
5. 当前 P2 `[+0.0109,+0.0720]` 为打包时采用值，后续仍可用 `sample_payload_xy.py` 继续复核。

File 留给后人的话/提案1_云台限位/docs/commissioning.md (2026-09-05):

# 分阶段调试与飞行验证方案

任何一步出现方向不确定、机械碰限位、舵机发热、BEC 掉压或高频抖动，都先 `DISARM`/断开舵机电源，排除后再继续。首次闭环绝不能直接装到已解锁的无人机上。

## 阶段 A：只接 MCU 与 IMU

1. 不接舵机电源，编译并下载固件。
2. 打开 115200 串口。上电时保持 IMU 静止，依次应看到：
   - `INFO,CALIBRATION_KEEP_STILL`
   - 约 2 秒后 `INFO,READY`
3. 水平放置，检查 `accel_norm` 约为 1，Roll/Pitch 接近 0。把板绕 X、Y 轴各转 +20°，核对对应角度方向和数量级。
4. 若静止水平时不是 `AZ≈+1 g` 对应的姿态，修改 `app_config.h` 的轴符号；若轴互换，则在 IMU 驱动输出处做轴置换。
5. 静止记录 60 秒：角度不应持续单向漂移，IMU 失败计数应始终为 0。

建议保存数据并计算：角度均值、标准差、峰峰值、加速度模长范围和串口丢帧率。

## 阶段 B：只验证 PWM 和机械行程

1. 拆下舵臂，接示波器/逻辑分析仪：PA0、PA1 应为 50 Hz，READY 时约 1500 µs。
2. 核对配置的 1000/1500/2000 µs 没有超出舵机厂商范围。
3. 断电后装舵臂，使 1500 µs 对应机构机械中位。
4. 先临时把软件行程收紧到 ±10°，低电流限制上电。发送 `SET,5,0` 后 ARM，观察 Roll 轴的缓慢响应；DISARM 后做 Pitch。
5. 分别手动轻微扰动每个框架，确认控制动作是“抵抗扰动”。若动作放大扰动，立即断电，并翻转对应 `k*ServoDirection`，不要尝试靠调小增益解决正反馈。

## 阶段 C：单轴闭环整定

机械锁住另一个轴，每次只整定一个轴。

1. 从保守参数开始：`GAIN,R,2.0,0.4,60,60`。
2. 缓慢倾斜底座 ±10°：逐步增加 `attitude_kp`，直到恢复速度够用但没有明显过冲。
3. 增加 `rate_kp` 提高阻尼和扰动抑制；一旦出现高频啸叫/舵机来回抖动，退回 30%～50%。齿隙导致的极限环不能靠继续加增益消除。
4. 最后按舵机能力提高 `max_target_rate` 和 `max_servo_slew`。先保证稳定，再追求速度。
5. Pitch 轴重复相同步骤。

串口增益只在本次上电有效。确定参数后写回 `AxisGains` 默认值或增加 Flash 参数存储。

## 阶段 D：双轴台架试验

1. 将整个无人机或等效底座固定在可控的两轴台架上，螺旋桨必须拆除。
2. 做阶跃：底座分别从 0° 转到 ±5°、±10°、±20°，记录 10%～90% 上升时间、超调、稳态误差。
3. 做正弦：0.2、0.5、1.0、2.0 Hz，各 ±10°。普通位置舵机在高频处性能明显下降是正常现象。
4. 同时扰动两个轴，检查轴间耦合、线束拉力和撞限位。
5. 用 NUC 同步记录 CUAV ATTITUDE 和云台遥测：

   ```bash
   python3 tools/cuav_gimbal_monitor.py \
     --gimbal /dev/serial/by-id/usb-STMicroelectronics_STM32_STLink-if02 \
     --mavlink udp:127.0.0.1:14550 \
     --csv gimbal_test.csv
   ```

## 阶段 E：地面整机与飞行试验

1. 拆桨整机通电 10 分钟，覆盖 NUC 高负载、图传发射、舵机往复，确认无 MCU 复位、CUAV 传感器干扰或电源过热。
2. 装桨但不解锁，短时低油门观察振动遥测。若静止角速度噪声显著上升，优先处理桨平衡和机械共振。
3. 首飞采用系留/安全区域、低高度悬停；准备独立云台断电开关。先保持 0°，再做很小的飞行 Roll/Pitch 动作。
4. 检查全程舵机命令是否长期接近 ±45°。接近限位表示机械行程、配平或安装零位不合理。
5. 逐步扩大飞行动作和任务时长，不在同一架次同时更改机械、滤波和增益。

## 故障定位速查

| 现象 | 首查项 | 处理方向 |
|---|---|---|
| `IMU_INIT` | WHO_AM_I、CS、SPI 模式、3.3 V | 检查接线与模块型号，应读到 `0x47` |
| 校准一直不结束 | 机架振动、陀螺偏置、AZ 方向 | 完全静置；打印原始量；放宽阈值只用于诊断 |
| 一 ARM 就撞限位 | 舵机方向、IMU 轴方向 | 断电，逐轴核对符号 |
| 低频来回摆 | 姿态增益过高、机构不平衡 | 降低 `attitude_kp`，先配平 |
| 高频抖动/啸叫 | 角速度增益、齿隙、IMU 振动 | 降低 `rate_kp`，改善结构/滤波 |
| NUC 一接入就复位 | USB 地环路、BEC 瞬态、电源并联 | 重做供电与接地，舵机独立供电 |
| 飞行加速时偏斜 | 加速度倾角误差 | 增强动态加速度抑制或加入 CUAV 前馈/EKF |

## 最小验收记录

每次参数冻结时保留：固件 Git 提交、机械版本、载荷质量/重心、舵机与 BEC 型号、PWM 范围、轴方向、滤波参数、两轴增益、60 秒静态日志、0.5 Hz 双轴台架日志、最长连续运行时间和峰值舵机电流。

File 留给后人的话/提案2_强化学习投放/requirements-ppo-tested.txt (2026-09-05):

cloudpickle==3.1.2
Farama-Notifications==0.0.6
filelock==3.32.5
fsspec==2026.7.0
gymnasium==1.3.0
Jinja2==3.1.6
MarkupSafe==3.0.3
mpmath==1.3.0
networkx==3.6.1
numpy==2.5.2
setuptools==84.0.0
stable_baselines3==2.9.0
sympy==1.14.0
torch==2.14.0
typing_extensions==4.16.0

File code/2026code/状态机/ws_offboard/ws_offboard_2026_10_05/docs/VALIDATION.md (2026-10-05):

# 本次验证结果

验证日期：2026-10-05。使用本机 WSL 的 Ubuntu 22.04、ROS 2 Humble、Python 3.10.12 环境。未连接实际飞控或 D435i。

| 检查 | 结果 |
| --- | --- |
| 四个包的 `package.xml` 与 colcon 发现 | 通过 |
| Python 源码语法与 Shell 语法 | 通过 |
| 四包 colcon 编译与安装 | 通过，C++17 任务节点成功构建 |
| 安装后的包和七个可执行入口发现 | 通过 |
| 安装后的任务 launch 参数枚举 | 通过，未启动进程 |
| 安装后的标定、遥测、相机预览帮助入口 | 通过，未连接硬件 |
| 安装后的 Python 模块、模型和配置资源查找 | 通过 |
| 航向格式、边界、错误值和缺失文件检查 | 通过 |
| 航向注入、包名与可执行入口集成检查 | 通过 |
| 模型安装目录与源码目录回退检查 | 通过 |
| 回归测试 | 9 项全部通过 |
| 中文注释与说明字符串检查 | 通过，无纯英文说明注释遗留 |
| C++ 注释翻译前后的非注释内容比较 | 通过，与原压缩包一致 |
| YAML 参数解析值比较 | 通过，与原压缩包一致 |
| 原遥测和消息频率工具的非说明语法树比较 | 通过，与原压缩包一致 |
| 三个模型逐字节 SHA-256 比较 | 通过，与原压缩包一致 |
| Python 运行依赖版本比较 | 通过，与原压缩包一致 |

## 构建环境说明

当前用户目录中的 setuptools 82.0.1 与 Humble 的 colcon 可编辑安装流程不兼容，首次构建报 `option --editable not recognized`。最终采用 Ubuntu 系统 setuptools 59.6.0，通过以下方式完成正常工作区脚本的编译：

```bash
PYTHONNOUSERSITE=1 CUADC_SKIP_ROSDEP_CHECK=1 bash scripts/build_onboard.sh
```

测试环境的 rosdep 数据库尚未初始化，因此本次明确跳过 rosdep 检查。实际构建已找到所需 ROS 依赖，但不据此宣称完成了机载环境的完整依赖安装。没有为此更改系统 Python 或安装新软件。

## 验证边界

本次验证没有执行完整视觉推理，也没有进行实际相机采集、飞控串口通信、舵机动作、定位与航向锁定、自动起降或实飞。测试环境未安装原视觉依赖中的 pyrealsense2 和 Ultralytics；这些需要在机载环境准备。

模型完整性检查、源码一致性检查与软件构建结果，不能代替原飞机的硬件适配和实机测试。本次交付是经过软件验证的源码组织版本。

## 复查命令

```bash
python3 scripts/validate_source.py
bash scripts/verify.sh
sha256sum -c SHA256SUMS
```

校验清单在源码打包时生成，不包含 `build/`、`install/`、`log/`、Python 缓存或打包后生成的实际标定文件。

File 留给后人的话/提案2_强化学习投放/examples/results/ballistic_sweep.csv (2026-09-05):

height_above_rim_m | vx_m_s | delay_s | fall_s | drift_x_m
0.7 | 0.0 | 0.0 | 0.3778363002900991 | 0.0
0.7 | 0.0 | 0.1 | 0.3778363002900991 | 0.0
0.7 | 0.0 | 0.2 | 0.3778363002900991 | 0.0
0.7 | 0.1 | 0.0 | 0.3778363002900991 | 0.03778363002900992
0.7 | 0.1 | 0.1 | 0.3778363002900991 | 0.04778363002900992
0.7 | 0.1 | 0.2 | 0.3778363002900991 | 0.05778363002900992
0.7 | 0.25 | 0.0 | 0.3778363002900991 | 0.09445907507252478
0.7 | 0.25 | 0.1 | 0.3778363002900991 | 0.11945907507252479
0.7 | 0.25 | 0.2 | 0.3778363002900991 | 0.14445907507252478
0.7 | 0.5 | 0.0 | 0.3778363002900991 | 0.18891815014504956
0.7 | 0.5 | 0.1 | 0.3778363002900991 | 0.23891815014504958
0.7 | 0.5 | 0.2 | 0.3778363002900991 | 0.28891815014504957
1.2 | 0.0 | 0.0 | 0.4947038418232699 | 0.0
1.2 | 0.0 | 0.1 | 0.4947038418232699 | 0.0
1.2 | 0.0 | 0.2 | 0.4947038418232699 | 0.0
1.2 | 0.1 | 0.0 | 0.4947038418232699 | 0.04947038418232699
1.2 | 0.1 | 0.1 | 0.4947038418232699 | 0.059470384182326995
1.2 | 0.1 | 0.2 | 0.4947038418232699 | 0.069470384182327
1.2 | 0.25 | 0.0 | 0.4947038418232699 | 0.12367596045581747
1.2 | 0.25 | 0.1 | 0.4947038418232699 | 0.14867596045581746
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

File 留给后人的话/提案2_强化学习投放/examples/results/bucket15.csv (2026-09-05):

policy | outcome | hit | error_m | landing_xy | release_xy | decision_s | release_s | fall_s | seed | blocked_reason | return | episode_s
random | miss | False | 0.11804813164844714 | [0.11725552202538912, 0.013656644545516884] | [0.1614776328294465, 0.043445369228637266] | 3.5 | 3.7033815454456507 | 0.4622859271479248 | 83000000 |  | -13.584600866055693 | 3.7033815454456507
random | miss | False | 0.13062754208983557 | [-0.10732705500264059, 0.07446111748350225] | [-0.1384009673467411, 0.08608222159216526] | 1.3 | 1.51887218088801 | 0.4959576380492992 | 83000001 |  | -14.98972172026985 | 1.51887218088801
random | miss | False | 0.23134793596306544 | [0.1050816909533602, 0.20610605449804992] | [0.10950324895770877, 0.272085823186079] | 1.8 | 2.0143748230810017 | 0.4408840858080289 | 83000002 |  | -16.45 | 2.0143748230810017
random | miss | False | 0.10441744051176595 | [-0.0028656317966227196, -0.10437811091140885] | [-0.006485133115237782, -0.10247957961753028] | 4.4 | 4.649753471910756 | 0.5250559254996726 | 83000003 |  | -11.914376176892613 | 4.649753471910756
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

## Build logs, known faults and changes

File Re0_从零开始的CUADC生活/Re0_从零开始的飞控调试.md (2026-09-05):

# CUADC：CUAV＋ArduCopter 飞控配置、调参、数传与RTK完整教程

> 从零建立可验证的飞行系统；重点讲内置AutoTune与官方Lua悬停QuickTune。

**版本：1.0｜资料核对：2026-09-05｜适用任务：多旋翼无人机侦察与救援。**

本教程面向第一次接触CUAV与ArduCopter的队员，也供已经会起飞、但尚不熟悉参数、日志和自动整定的成员查阅。主线是：**硬件和供电正确→静态配置与传感器可信→通信和导航可靠→机械/滤波健康→自动整定→载荷及速度包络→全任务和失效验收。**

没有给出可直接导入陌生飞机的整机参数，也没有把尚未实测的O4航线、12m/s或全流程时间写成现有能力。V6X只作为接口例子；你们实际CUAV型号、固件、动力、接收机及数传仍须登记。

## 怎样使用这份教程

| 你的任务 | 建议阅读路径 | 应交付什么 |
|---|---|---|
| 完全新人 | 第1～20章，附录A/B/J | 身份、接线、校准、无桨检查记录 |
| 配置数传和RTK | 第21～35章，附录F的基站卡 | 端到端链路和定位验收 |
| 专门负责调参 | 第36～52章，附录C/D | 参数前后差异、日志与载荷测试 |
| 重点学Lua悬停自动调参 | **第45～50章**，第41/51章对照 | 脚本版本、开关、保存/回退、异常操作卡 |
| 接任务状态机 | 第53～57章，附录I | 坐标/速度/时间/故障联合验收 |
| 现场排障与交接 | 第58～64章，附录F/G | 故障证据、复盘和版本冻结 |
| 不接硬件先练习 | 第62章，附录E | 运行离线工具并解释输出 |

主文使用三类标记：**源码事实**指上传v11或固定官方源码的行为；**资料核对**指官方文档/发布；**教学算例/工程建议**有明确假设，需要实机验证。参数表中的默认值仅属于写明的版本，不保证等于你们当前持久化值。

引用如[S05](#s05)、[G02](#g02)可跳至附录H，再进入官方页面。源码行号对应[P1](#p1)的文件指纹。所有实践文件在配套ZIP中，也在附录E/F中提供主要源码和记录表。

### 先记住四个区别

**AutoTune不是AUTO模式；Lua QUIK不是C++ QWIK；命令ACK不是物理动作完成；RTK Fixed不是整机飞行质量证明。**

调参前必须已基本可飞、能安全中止、具备对应试验空间。所有电机台架检查先拆桨，真实调参不在桶上方的1.3m任务高度首次尝试。正式比赛不得把赛前人工调参流程夹进自主任务。[S05](#s05) [G02](#g02) [G03](#g03)

## 目录

- [1. 调飞控的目标：让任务有可靠的物理执行基础](#c01)
- [2. 零基础先认识这些名词](#c02)
- [3. 把你们的任务要求翻译成飞控验收项目](#c03)
- [4. 学习、台架、试飞、比赛必须分开](#c04)
- [5. 版本管理：4.6 的参数不能按 4.7 的单位照抄](#c05)
- [6. Mission Planner：从连接到真正读懂界面](#c06)
- [7. 参数备份、差异审阅与回滚](#c07)
- [8. CUAV 接口：以实物型号和对应硬件定义为准](#c08)
- [9. 电源：很多“飞控报错”其实从这里开始](#c09)
- [10. 机架、重心、安装与振动先于 PID](#c10)
- [11. 机架类型、输出映射与无桨电机测试](#c11)
- [12. PWM、DShot、ESC 遥测与输出组冲突](#c12)
- [13. 加速度计与飞控安装朝向](#c13)
- [14. 陀螺仪、温度与 IMU 振动](#c14)
- [15. 罗盘、航向与磁干扰](#c15)
- [16. 遥控校准、飞行模式和辅助开关](#c16)
- [17. 安全按钮、解锁检查与紧急停止](#c17)
- [18. 双投放舵机：从飞控输出到水瓶脱离](#c18)
- [19. 日志、SD 卡与“必须保留什么”](#c19)
- [20. 第一架次应做什么，而不应做什么](#c20)
- [21. 串口、USB、I²C、CAN：从电气层开始排查](#c21)
- [22. 推荐的系统分工：遥控、数传、伴随计算机、O4 分开](#c22)
- [23. SiK 数传：从配对到实际链路验收](#c23)
- [24. CUAV 专用数传、网络数传和供电问题](#c24)
- [25. 带宽预算、30 Hz 导航流与消息率争用](#c25)
- [26. MAVLink 系统 ID、路由、连接独占与信息安全](#c26)
- [27. GNSS 基础：3D Fix、Float、Fixed 分别说明什么](#c27)
- [28. RTK 的两种“基站”：固定地面基站与机载移动基线](#c28)
- [29. 固定 RTK 基站：从安装到坐标确定](#c29)
- [30. 机载 RTK rover：UART 与 DroneCAN 两条配置路线](#c30)
- [31. 通过 Mission Planner 给飞机注入 RTK 修正](#c31)
- [32. NTRIP：网络修正不是“插上网就 Fixed”](#c32)
- [33. 双天线航向、杆臂与 FRD/FLU 的符号](#c33)
- [34. EKF 源、低空高度与参考点](#c34)
- [35. RTK 的验收：固定解率只是第一项](#c35)
- [36. 控制环：先分清自己正在调哪个环](#c36)
- [37. 怎样用日志判断“调参不对”](#c37)
- [38. 推力曲线、悬停油门与载荷变化](#c38)
- [39. 滤波：为什么应在自动整定前完成](#c39)
- [40. 手动初调：目标是得到可安全辨识的基线](#c40)
- [41. 三种自动调参：必须先选对名字](#c41)
- [42. 内置 AutoTune：准备、参数与版本差异](#c42)
- [43. 内置 AutoTune：完整的执行、试飞与保存流程](#c43)
- [44. AutoTune 卡住、失败或效果不佳怎么办](#c44)
- [45. GitHub 上的悬停 Lua 自动调参：确认脚本，再安装](#c45)
- [46. Lua QuickTune 的 15 个参数逐项解释](#c46)
- [47. Lua QuickTune 三段开关：停止、开始、保存](#c47)
- [48. Lua 算法推导：它为什么能在悬停中整定](#c48)
- [49. 从源码读懂 Lua：变量、API、状态与保护](#c49)
- [50. Lua QuickTune 的异常与回退：比“怎么开始”更重要](#c50)
- [51. 内置 C++ QuickTune：为什么不能照 Lua 参数表配置](#c51)
- [52. 整定完成后的验收：空载、A1、A2、双瓶](#c52)
- [53. 高度、Loiter 与位置外环：AutoTune 之后还有工作](#c53)
- [54. GUIDED、MAVROS 与你们的 v11：飞控必须满足哪些条件](#c54)
- [55. 12 m/s 转场：必须先算加速度与刹车距离](#c55)
- [56. 返航与降落：HOME、EKF原点和接地点](#c56)
- [57. 失效保护：不能只依赖 ROS 状态机](#c57)
- [58. 常见报错（一）：连接、校准与不能解锁](#c58)
- [59. 常见报错（二）：飞起来之后的控制问题](#c59)
- [60. 常见报错（三）：RTK、数传、NAV30 与任务问题](#c60)
- [61. 六个完整教学案例：先建立假设，再修改配置](#c61)
- [62. 阶段实践：离线工具怎样帮助调飞控](#c62)
- [63. 从第一天到比赛放行的阶段验收](#c63)
- [64. 团队传承：每次调参必须能回答的十个问题](#c64)
- [附录 A. 新飞控从开箱到基础放行：可执行的配置工作单](#appendix-a)
- [附录 B. 参数阅读方法：单位、枚举、位掩码与版本迁移](#appendix-b)
- [附录 C. 一次完整的日志复盘工作坊](#appendix-c)
- [附录 D. 必须掌握的数学与工程估算](#appendix-d)
- [附录 E. 完整离线实践源码](#appendix-e)
- [附录 F. 十份可复制的团队记录模板](#appendix-f)
- [附录 G. 30个阶段性练习与参考答案](#appendix-g)
- [附录 H. 官方资料与固定版本源码](#appendix-h)
- [附录 I. v11源码阅读索引：飞控调参怎样影响任务](#appendix-i)
- [附录 J. 术语速查：从报错到正确的系统层](#appendix-j)
- [附录 K. 交付验证与未验证范围](#appendix-k)

---

## 1. 调飞控的目标：让任务有可靠的物理执行基础

CUADC 多旋翼侦察与救援不是单纯“飞机能悬停”。一架能完成任务的飞机，要先后满足几种不同要求：满载起飞、较快转场、低速搜索、低空收敛、静稳投放、载荷突变后恢复、侦察、返航和准确降落。不同环节约束的是不同子系统。

**飞控整定的任务是让实际运动可靠地跟踪合理的指令，不是把不合理指令变成合理指令。**

| 现象 | 首先检查的层级 | 不应该先做的事 |
|---|---|---|
| 一解锁就侧翻 | 电机顺序、旋向、桨型、机架类型、姿态方向 | 运行 AutoTune |
| 图像桶坐标整体偏一侧 | 相机外参、坐标约定、航向、时间延迟 | 增大横滚 P |
| 平稳但悬停位置缓慢漂移 | GNSS/EKF/航向、外环、风、定位基准 | 直接增加 D |
| 高速到点后冲过目标 | 制动距离、轨迹限加速度、实际速度 | 只缩小航点半径 |
| 舵机 ACK 成功但瓶子未掉 | 供电、机构卡滞、行程、载荷反馈 | 再调姿态环 |
| 一投掉水瓶高度上冲 | 推力余量、重量变化、垂向控制、动作时序 | 把全部增益统一加倍 |

整个教程按“先能正确感知，再能稳定控制，最后能可靠执行任务”的顺序组织。算法名不是验收结果；要用日志、重复试飞和明确的失效处理证明改动有效。[S01](#s01)[S02](#s02)

## 2. 零基础先认识这些名词

**飞控硬件**是 CUAV 的电路板、传感器和接口；**ArduCopter 固件**是运行在板上的程序；**Mission Planner** 是地面站；**MAVLink** 是通信协议；**MAVROS** 是 ROS 与 MAVLink 之间的接口组件。它们不是同一件东西。

**IMU** 提供角速度和比力。陀螺仪不直接告诉飞机“现在位于哪里”；加速度计读数也不等于经过地球坐标变换、减去重力后的运动加速度。

**AHRS/EKF** 把 IMU、磁力计、气压计、GNSS 等信息组合成姿态、速度、位置估计。**RTK** 改善卫星定位解，不是独立的飞行控制器。**GPS for Yaw** 使用天线基线提供航向，又是另一种功能。

**P、I、D、FF** 是控制器中的比例、积分、微分和前馈项。**滤波器**用于处理噪声，但会引入动态影响；滤得越狠不一定越稳定。

**解锁 armed** 代表飞控允许动力系统进入工作状态。**安全按钮 safety switch**、**电机紧急停止 emergency stop**、**飞行模式切换**和**物理断电**不是同一种保护。

**RC 输入通道**表示接收机上送的控制信息；**SERVO 输出通道**表示飞控向电机/舵机输出的功能。`RC9_OPTION` 与 `SERVO9_FUNCTION` 没有天然的一对一关系。

**AutoTune** 是自动整定机制；**AUTO** 是执行机载任务的飞行模式；**GUIDED** 是接受外部目标指令的模式。你们 v11 主要走 GUIDED，不是把整条任务上传成 AUTO 航点。[S03](#s03)[S04](#s04)[P1](#p1)

## 3. 把你们的任务要求翻译成飞控验收项目

【源码事实】上传的 v11 在 RELEASE 前要求水平速度不超过 0.15 m/s、垂直速度绝对值不超过 0.10 m/s、横滚和俯仰**各自**不超过 8°、角速度向量模长不超过 10°/s，并连续满足 0.50 s。它还检查目标身份、区域、高度和投放口位置。[P1](#p1)

这些是状态机判断门限，不是已经测得的飞机性能，也不是 ArduCopter PID 参数。

由此可以设计任务相关测试：固定目标点附近能否重复进入低速状态；阵风后能否及时恢复；一瓶释放后多久再次稳定；空载时会不会出现较满载更快的振荡。把实际 RELEASE 等待原因统计出来，才知道需要改飞控、视觉还是动作设计。

例如，持续侧风要求飞机以 11° 横滚才能保持位置，即使姿态控制非常好，也可能一直无法通过 8° 门限。此时问题不是“P 不够大”，而是任务门限与飞行环境不匹配。处理应是重新评估环境、任务策略及安全条件，不是无条件放宽门限。

本文不假定你们已经把非任务区速度改成 12 m/s，也不假定 O4 侦察路线已经验证。原 v11 默认仍为较低转场速度和六点 RGB 拍照。关于 12 m/s 的制动与时间计算见第 55 章。

**需要补齐的实机信息**：CUAV 型号及硬件版本、ArduCopter 完整版本/构建标识、机架与桨直径、空机和两瓶载荷质量、ESC 型号与协议、电池、GNSS/RTK 型号、遥控协议、数传型号、供电图、当前全参数和一段原始 BIN。没有这些，不能负责任地给出一套“直接导入即可飞”的完整参数。

## 4. 学习、台架、试飞、比赛必须分开

把测试分成五级：

| 等级 | 内容 | 放行条件 |
|---|---|---|
| L0 离线 | 参数文件、日志、数学和合成数据练习 | 不连接飞控、不发送控制命令 |
| L1 无桨台架 | 电源、传感器、通信、RC、舵机、故障链 | 所有螺旋桨拆下，载荷有支撑 |
| L2 隔离仿真 | SITL、异常注入、模式与参数保存试验 | 与真机串口、网络路由完全隔离 |
| L3 开阔场试飞 | 基础悬停、滤波、AutoTune/QuickTune、制动 | 合格飞手、观察员、清场、可中止方案 |
| L4 任务验收 | 满载/单瓶/空载，完整任务和异常分支 | 前三级已通过，逐级提高复杂度 |

**任何电机测试和电调配置都先拆桨。** 不允许用手抓住带桨飞机证明控制方向正确；不把绑在桌上的强约束机体当自由飞行模型整定；不在室内、桶上方 1.3 m 或狭窄比赛走廊第一次做自动调参。

每次带桨试飞前，飞手必须能回答：如何立即结束当前调参？如何切到已经验证的可控模式？定位不可用时哪个模式仍可用？什么情况下必须落地？谁负责宣布中止？安全开关是否会切断所需的动力，而不是仅改变界面状态？

调参阶段的人工开关操作是**赛前试验**，不要把它放进要求自主执行的正式比赛过程。比赛现场要求以当轮正式规则和裁判说明为准；本教程不是参赛资格或法规解释。[S05](#s05)[P2](#p2)

## 5. 版本管理：4.6 的参数不能按 4.7 的单位照抄

【资料核对】官方仓库的 `Copter-4.7.1` 发布条目标为非预发布、稳定版，发布日期为 2026-09-04。本文查阅日为 2026-09-05。**这不代表你们正在使用该版本，也不构成比赛前升级建议。**[G01](#g01)

ArduCopter 4.7 对大量参数进行了改名和 SI 单位转换。地面站旧截图、旧教程、旧参数文件与新固件混用，是非常实际的风险。[G06](#g06)[G07](#g07)

| 项目 | 4.5/4.6 常见旧写法 | 4.7 对应写法 | 阅读规则 |
|---|---|---|---|
| 水平航点速度 | `WPNAV_SPEED`，cm/s | `WP_SPD`，m/s | 1200 cm/s 与 12 m/s 相等 |
| 水平航点加速度 | `WPNAV_ACCEL`，cm/s² | `WP_ACC`，m/s² | 数值通常除以 100 |
| 航点半径 | `WPNAV_RADIUS`，cm | `WP_RADIUS_M`，m | 不只是换名字 |
| 最大倾角 | `ANGLE_MAX`，centideg | `ATC_ANGLE_MAX`，deg | 3000 与 30 表达同一角度 |
| 横滚最大角加速度 | `ATC_ACCEL_R_MAX`，centideg/s² | `ATC_ACC_R_MAX`，deg/s² | 不是线加速度 m/s² |
| 俯仰/偏航最大角加速度 | `ATC_ACCEL_P_MAX/Y_MAX` | `ATC_ACC_P_MAX/Y_MAX` | 同样检查角度单位 |
| 最后下降速度 | `LAND_SPEED`，cm/s | `LAND_SPD_MS`，m/s | 50 与 0.50 表达同一速度 |
| Loiter 速度 | `LOIT_SPEED`，cm/s | `LOIT_SPEED_MS`，m/s | 模式不同，不等于 GUIDED |
| 起飞前检查 | `ARMING_CHECK`：旧版 bit 0 表示全部 | `ARMING_SKIPCHK`：0 表示不跳过 | **位掩码语义相反，不能复制数值** |

这个表是查找入口，不是自动转换器。尤其位置控制器 `PSC_*` 的迁移涉及名称、单位和某些增益缩放，不能把所有值机械地除以 100。固件内置迁移代码、对应版本参数说明和实际读回结果必须一起核对。

一些网页已换成新参数名，但段落仍残留旧单位或旧数字。本文遇到矛盾时明确区分“网页描述”和“固定版本源码”，不把网页中的旧量纲当成真机配置依据。附录 B 给出更完整的版本阅读方法。

建议锁定三件东西：**飞控固件版本/构建、地面站版本、脚本提交版本**。准备好上一版已验收 `.apj`、参数备份、脚本和日志；实际降级也应先确认参数兼容，不能只刷新固件而把新参数结构原样留下。

## 6. Mission Planner：从连接到真正读懂界面

Mission Planner 是配置和诊断工具，不是“配置向导点完就自动安全”的认证程序。本文以 Windows 上常见操作为例，菜单可能随版本显示为 SETUP/CONFIG/DATA 或 Initial Setup/Config-Tuning/Flight Data。

首次操作顺序：

1. 全部拆桨；确认供电、线束无短路；不启动 MAVROS 和其他串口客户端。
2. 使用可靠 USB 数据线连接，选择实际出现的 COM 端口。充电线不能代替数据线。
3. 等待参数完整下载，查看消息区中真实固件版本、板型和报错。
4. 保存一次全参数和消息记录，作为接手这架飞机时的原始状态。
5. 在 HUD 中缓慢改变机体姿态，确认显示方向和实际动作一致，再进入后续校准。

常用页面分工：

| 页面 | 用途 | 典型陷阱 |
|---|---|---|
| Mandatory Hardware | 机架、加速度计、罗盘、遥控 | 校准顺序混乱或未重启 |
| Optional Hardware | 电源、数传、RTK、传感器 | 按别的硬件套型号 |
| Full Parameter List/Tree | 参数原名、帮助、读写 | 写入后未读回；旧元数据 |
| DATA / Messages | STATUSTEXT、模式、解锁状态 | 只截最后一行错误 |
| DataFlash Logs | 机载 BIN 下载与分析 | 把地面 tlog 当全采样日志 |
| Radio / Aux Function | 开关与输入核对 | 同一开关绑定不同危险功能 |

写入参数后要确认：是否成功回显、是否注明需重启、重启后是否保留、功能是否通过无桨验证。**界面字段改了，不等于飞控已经使用了新值。**[S06](#s06)[S07](#s07)

## 7. 参数备份、差异审阅与回滚

建议每次变更保存四份信息：变更前全参数、变更后全参数、变更理由和对应日志。目录可用：

```text
vehicle_V6X_01/
  manifest.md
  firmware/
  params/
    20260905_01_before.param
    20260905_02_after_notch.param
    20260905_03_after_quicktune.param
  scripts/
  flights/
    F001_empty_hover/
    F002_two_payload_hold/
  changes.csv
```

参数文件通常是名称和值；还可能有注释、逗号或制表符，以及 QGroundControl 的 system/component/type 列。**不要用简单“按空格取第二列”的脚本处理所有格式。**本教程的离线解析器见第 62 章，遇到重复名称、非有限值和不认识的格式会拒绝猜测。

变更记录至少说明：哪个假设、只改了哪一类参数、为何预期有效、可能副作用、如何判失败、怎样回滚。把“感觉稳了”改成“相同电池状态、相同载荷、相似风况下，角速度跟踪与动作后收敛时间均改善，电机温度及饱和未恶化”。

别把全参数从另一架飞机导入作为初始设置。其中包含板级引脚、校准、传感器设备 ID、机架输出、RC、失效保护、导航源等。即使同型号 CUAV，也不代表传感器校准、线束和执行器一致。

此外，飞控 `.param`、ROS `.yaml`、GNSS 接收机内部配置、数传配置、Lua 的持久参数是不同的配置域。备份一个文件不能覆盖整架飞机。[S07](#s07)

## 8. CUAV 接口：以实物型号和对应硬件定义为准

CUAV 不同型号的接口和固件目标可能不同。**本文用 V6X 的公开映射作教学例子，不能把它当你们尚未确认型号的实机或全部 CUAV 飞控的接线表。**同名系列还可能有硬件修订、载板与固件目标区别。

官方 V6X 页面给出的串口映射示例是：`SERIAL0` 对应 USB；`SERIAL1` 对应 TELEM1；`SERIAL2` 对应 TELEM2；`SERIAL3/4` 对应 GPS1/2；还有 TELEM3、USER、DEBUG 等接口。具体 MCU UART 名不是配置时最先需要记住的东西，**实物接口→SERIAL编号→协议→对端**才是接线表的核心。[S08](#s08)

| 实物接口 | 计划接入 | 必须核对 |
|---|---|---|
| POWER | 匹配的电源模块 | 电压范围、模拟/数字测量、供电能力 |
| TELEM | 数传或伴随计算机 | TX/RX/GND、逻辑电平、流控、SERIAL 映射 |
| GPS | GNSS 及可能共线的罗盘 | UART 与 I²C 针脚不能混接 |
| CAN | DroneCAN GNSS/电源/ESC | H/L、终端、电源、节点协议 |
| RCIN / 支持串口 | RC 接收机 | SBUS/CRSF 等协议及电平要求 |
| MAIN / AUX / M / A | 电机和投放舵机 | 输出功能、协议分组、独立供电 |

**不要仅凭插头能插进去或导线颜色相同判断兼容。**对照针脚图，用万用表确认地线、电源，确认接口看的方向是正面还是线束端。TTL UART 不等于 RS-232，5 V 供电端也不代表信号脚耐受 5 V。

V6X 的厂商页面与 ArduPilot 页面在部分输出分组、DShot 支持表述上存在差异。因此本文不把“A1～A8 全都支持某协议”写成普遍保证。以你们**实际板型的固定固件 hwdef、厂商修订说明及无桨测试**共同确定。模拟舵机与 DShot 电机不能在受相同定时器约束的输出组中随意混用。[S08](#s08)[S09](#s09)[G10](#g10)

## 9. 电源：很多“飞控报错”其实从这里开始

典型系统至少有动力电源、飞控逻辑电源、舵机电源、伴随计算机电源和图传电源。它们可以共用电池，但不应把各自大电流直接压到飞控外设口上。

```text
电池 ── 主电源/电流测量 ── ESC与电机
  ├── 合适的飞控电源模块 ── CUAV
  ├── 合适的稳压电源 ── NUC / D435i
  ├── 合适的稳压电源 ── O4
  └── 合适的 BEC ── 投放舵机电源轨
```

这是功能图，不是可直接照焊的针脚图。电压、持续电流、峰值电流、保险和是否需要隔离必须按器件规格设计。信号通常需要共同参考地，但高电流回路应避免穿过敏感信号地线。两个 BEC 的正极也不能未经设计并联。

重点做组合负载检查：O4 发射、NUC 推理、RTCM 注入和两路舵机动作同时发生时，飞控有无重启、GNSS 是否重连、USB 是否掉线、电源温度是否异常。无桨台架不足以复现电机满负载压降，应把后续安全试飞日志纳入验证。

模拟电压校准的基本关系是：

\[
M_{new}=M_{old}\frac{V_{reference}}{V_{display}}
\]

它仅适用于对应的线性比例参数和可靠的参考测量。先确认 `BATT_MONITOR` 类型及引脚/总线正确，再调整比例；数字电源模块不要盲目套模拟模块的 `BATT_VOLT_PIN`。

电流校准需要区分零偏与比例。充电器回充量只能作为带有损耗、静置用电等影响的辅助核对，不能把一次差值精确等同于飞行电流传感器误差。电池低压和容量失效保护必须基于真实电池、负载压降与返航余量，而不是只按“6S”给全队同一个电压值。[S10](#s10)[S11](#s11)[S12](#s12)

## 10. 机架、重心、安装与振动先于 PID

检查桨是否损伤、安装方向是否正确、电机轴是否弯曲、螺丝是否过长顶到绕组、飞控减振是否被硬线束跨接、GNSS 支架是否摆动、瓶子和挂架是否相对机体运动。松散的机构会形成控制器没有建模的弹性自由度。

两瓶水的质量与位置会改变重心、转动惯量和悬停推力。一瓶掉落后还可能左右不对称。应测量：空载、A1 挂载、A2 挂载、双瓶四种静态配置。**“单瓶状态”不一定只有一种。**

将电池滑动位置用于配平可以改善稳态，但每次改动后要更新重量与重心记录；不能边改机械边调 PID，最后说不清哪个改动起作用。

小角度与刚体力臂例子：飞控参考点下方 0.32 m 的机构，8° 倾斜会使这一段垂向力臂产生约 `0.32×sin(8°)=0.0445 m` 的水平投影。姿态稳定对投放精度重要，但实际投放中心还取决于机构标定和水瓶脱离方式。[P1](#p1)

不要把飞控物理中心、EKF 报告位置参考点、GNSS 天线相位中心、整机重心、相机光心和瓶子质心当成同一点。后续第 33、54 章分别讲导航和任务外参。

## 11. 机架类型、输出映射与无桨电机测试

先在实际固件中选择正确的机架类别和布局，例如四旋翼 X；再对照该布局的官方电机图确定电机编号、转向和安装位置。Mission Planner 的电机测试 A/B/C/D 顺序不应凭直觉等同于固件电机 1/2/3/4。[S13](#s13)

无桨测试要逐个记录：点击哪个测试输出、实际哪个电机转、旋向如何、开始可靠旋转的输出范围。只在所有输出均一致后，才允许安装正确对应的桨。

`SERVOx_FUNCTION` 决定输出用途。输出口本身的编号和电机功能编号是两回事。重映射后尤其要检查投放舵机 9/10 没有占用电机功能，也没有被其他功能持续覆盖。

错误机架/方向的典型特征是离地瞬间快速翻滚，而不是缓慢收敛差。此时继续增加增益会使错误反馈更强。正确处理是停止试飞，回到输出与传感器方向检查。

**阶段实践 A：**画一张俯视机架图，标出前方、四个电机功能编号、实际输出口、旋向、桨型、两瓶位置和飞控朝向。另一个队员仅根据图复核，无需操作者口头提示即可核对全部接口。

## 12. PWM、DShot、ESC 遥测与输出组冲突

PWM 通过脉宽表达命令；DShot 通过数字帧表达命令。它们的配置、标定方法和诊断方式不同。**DShot 不做传统油门高低端点校准**；是否使用何种 DShot 速率，应依据 ESC、飞控输出支持和布线可靠性，而不是越高越好。[S14](#s14)[S15](#s15)

不要把 `MOT_SPIN_ARM`、`MOT_SPIN_MIN`、油门曲线与遥控油门校准混为一谈。前者与电机可重复启动、低输出控制余量有关；RC 校准是输入映射。具体参数值需要通过对应动力系统验证。

ESC 遥测可能经独立串口、双向 DShot 或 DroneCAN 返回。配置“数字电调”不代表飞控已经收到 RPM。还要检查电机极数/电气转速到机械转速换算、每路更新是否连续、个别 ESC 是否失联。[S16](#s16)

同一输出定时器组常有共同的速率/协议限制。你们 SERVO9/10 需要模拟舵机脉宽时，不可因启用另一输出的 DShot 而间接把这两路也改成数字电机信号。

验证顺序是：无桨通信和单电机输出→转速与温度反馈合理→基本飞行日志→必要的 RPM 跟踪陷波。不要一次同时更新 ESC 固件、换协议、改极数、开双向遥测和运行 AutoTune。

## 13. 加速度计与飞控安装朝向

先配置实际安装方向，再进行对应校准。六面加速度计校准估计传感器偏置和比例等误差；“Calibrate Level”用于把机体水平基准与实际安装微小偏差关联，两者不是互相替代。[S17](#s17)

校准应在不解锁、不晃动的条件下进行。每个姿态放稳后再确认，不需要快速甩动。柔软支架、持续震动的桌面和未固定的线束都会降低质量。

完成后用独立物理直觉检查 HUD：机头上抬、右侧下压、水平放置时，显示是否一致。不能只看“校准成功”弹窗。

机体基准面不是随手找的桌面，也不一定是相机底面。用团队约定的结构基准，并记录电池和载荷是否影响机体支撑姿态。改变飞控安装角、软支架或载板后需要重新评估。

**错误做法：**因为飞机向左漂，就把 AHRS 安装角改到看起来不漂。这样可能同时污染任务视觉外参和姿态估计。应先分清传感器水平基准错误、罗盘误差、风和位置环行为。

## 14. 陀螺仪、温度与 IMU 振动

上电时保持机体静止，让初始陀螺仪零偏估计有正常条件。把刚从低温环境拿出的飞机立即起飞，与热稳定后的控制和高度表现可能不同，应记录环境和飞控温度。[S18](#s18)

振动有两个不同观察方向：加速度计 VIBE/Clip 反映测量环境；高频角速度日志与频谱反映控制器输入的噪声及结构/电机频率。VIBE 较小不自动证明所有角速度噪声都小。

官方将约 30 m/s² 以下描述为通常可接受的振动水平，超过 60 m/s² 常伴位置或高度问题。这里仅作为排查信号，不能变成“29.9 必然安全、30.1 必然失败”的比赛验收线。还应看裁剪计数是否在飞行阶段持续增长、多 IMU 是否一致、噪声是否与油门相关。[S19](#s19)

先消除松动、不平衡、线束跨接减振、共振支架，再处理滤波。不使用高 D 去补机械松动，也不把所有滤波频率降得很低来掩盖裁剪。

温度校准属于进阶工作，只有在对应板型和流程明确、能控制实验环境时开展；不要把用户自行烘烤硬件当作普通新手必做步骤。

## 15. 罗盘、航向与磁干扰

罗盘校准应在远离大块铁磁物体、汽车、钢筋密集地面及高电流设备的环境中进行。先完成姿态方向与加速度计校准，再校准磁力计。外置罗盘的设备 ID、优先级、安装方向与使用状态都应记录。[S20](#s20)[S21](#s21)

对 CUADC，航向错误还会旋转整条 field 航线。若前方距离为 L，航向误差为 δ，横向偏差近似 `L sinδ`。L=60 m、δ=2° 时约 2.09 m。**定位达厘米级并不能抵消两度航向误差。**

静态校准合格以后，还要检查电流相关磁干扰：电池线绕过罗盘、O4/数传供电、舵机动作和动力负载是否使估计航向变化。保持线束布局一致，避免赛前临时捆扎改变电流环路。

不是罗盘越多越好；也不是把内部罗盘全禁用就必定正确。应根据安装环境、健康状态和日志确定选择，并保留设备 ID。自动识别安装方向也可能在磁场被污染时失败。

“马桶圈”式位置绕圈可由航向错误引起，但还可能与定位和外环有关。不要只靠现象给出唯一诊断，更不要直接增大 Loiter P。先比较实际机头方向、飞控航向、GNSS 轨迹和期望加速度方向。

## 16. 遥控校准、飞行模式和辅助开关

校准 RC 输入时让飞控记录每个通道的最小、最大和中位，确认 RCMAP 对应正确、摇杆反向与死区合理。除油门外，摇杆回中应落在死区内；发射机的 trim、混控和曲线不能让调参脚本持续误判飞手在操作。[S22](#s22)

建议把操作权限分开，不用一个开关叠加多种危险功能：

| 功能 | 设计要求 |
|---|---|
| 模式开关 | 至少有已验证的人工可控模式和任务模式 |
| 紧急停止 | 明确、独立、可盲操作，理解恢复后电机可能恢复输出 |
| AutoTune / QuickTune | 赛前临时独立分配；两种整定不得共用运行 |
| 舵机手动测试 | 仅无桨台架，正式比赛前解除不需要的绑定 |
| 任务启动确认 | 与真正解锁、比赛计时顺序协调，不暗含调参启动 |

例如 Lua QuickTune 使用 `RC7_OPTION=300` 时，含义是“RC7 驱动 Scripting1 辅助功能”；`QUIK_RC_FUNC=300` 读取这个功能，不是读取第 300 个 RC 通道。

开关的机械低/中/高位置，与接收机上报 PWM 的大小可能因反向而颠倒。必须逐位置看输入和功能状态，并贴标签。启动时低位、失联时接收机行为也要验证。不能靠经验认定“往上就是保存”。[S23](#s23)

## 17. 安全按钮、解锁检查与紧急停止

安全按钮、`armed` 状态和电机是否实际产生推力构成不同层级。某些输出可能被安全掩码豁免；舵机供电也可能不受电机停转控制。比赛所要求的安全开关应通过真实功能验证，而不是只看到地面站出现 SAFE 字样。[S05](#s05)[S24](#s24)

保留正常起飞前检查。旧版本的 `ARMING_CHECK` 和新版本的 `ARMING_SKIPCHK` 要按第 5 章理解，**不要照网上常见“设0解决无法解锁”教程处理所有错误**。检查被关闭后，故障并没有消失，只是不再被拦住。

遇到 PreArm 报错时，记录完整首个错误、当前模式、电源来源、是否有桨、位置环境、固件版本以及前一次改动。解决原因后再重试，不以反复解锁代替定位。

紧急停止开关要在无桨台架上验证：触发是否确实停止所需输出、解除是否会在仍 armed 时恢复动力、飞控和舵机供电是否仍在、飞手能否确定当前状态。真实飞行中动力切断会导致坠落，只作为与风险相称的紧急手段；普通调参中止优先使用调参专用停止/回退及已验证飞行模式。

**阶段实践 B：**让两名队员分别执行“解释开关—台架操作—读回状态”，互相检查。任何人说不清某开关解除后的行为，该配置不得放行。

## 18. 双投放舵机：从飞控输出到水瓶脱离

【源码事实】v11 对 SERVO9/10 使用 1200 μs 挂载、1500 μs 释放、保持约 0.7 s 后回位。这是当前软件契约，**不是所有舵机和投放机构的通用行程**。[P1](#p1)

设置专用输出时，要确认实际针脚、`SERVOx_FUNCTION`、脉宽范围、协议组及安全状态允许方式。`MAV_CMD_DO_SET_SERVO` 需要输出功能可被该命令控制；已用于电机或其他主动功能的输出不能按普通舵机测试处理。[S25](#s25)[S26](#s26)

台架顺序：先空机构、支撑住载荷、确认机械限位，再逐步检查挂载—释放—回位。观察舵机是否持续堵转、BEC 电压是否下降、一次释放是否会碰到另一瓶、信号失联/飞控重启后机构位置是否安全。

三个“成功”必须分开：

- 命令发送成功：伴随计算机发出了请求。
- 飞控 ACK：飞控接受了请求或返回执行结果。
- 物理释放成功：水瓶实际离开且落点合格，需要独立观测或传感器证据。

因此不要用“ACK 次数=成功投放次数”来判断机构可靠性。v11 已把超时/迟到 ACK 视为物理状态不确定；现场还应验证断电、回位失败和载荷卡住时的处理。首次调参中不释放水瓶，首次投放试验也不同时运行调参。[P1](#p1)

## 19. 日志、SD 卡与“必须保留什么”

机载 DataFlash BIN 记录飞控实际状态，是调参主要证据；地面 `.tlog` 记录收到的 MAVLink 消息，会受链路、消息频率和丢包影响；ROS bag 则记录伴随计算机看到的状态与目标。三者应按同一架次归档，不能互相替代。[S27](#s27)[S28](#s28)

每次试飞至少保留：BIN、前后参数、地面消息、载荷配置、电池编号、风况估计、操作时间线。任务联调还要记录 setpoint、odom、视觉消息时间戳、状态机状态和释放命令/ACK。

`LOG_DISARMED` 有利于记录上电和地面初始化，但会增加存储和写入。高频原始 IMU、批采样和完整 PID 日志也有带宽与 CPU/SD 负担。根据本次试验问题选择，确认没有持续日志丢弃和主循环过载。

日志下载在地面进行。不要在快速任务或 QuickTune 时同时通过低速数传下载大日志。传输挤占带宽可能同时影响 RTCM 和状态消息，制造出“GPS 和视觉同时不稳定”的假象。

**阶段实践 C：**不飞行，先学会导出一次全参数、保存消息窗口并打开已有示例日志。练习找出固件版本、模式变化、armed 状态和日志起止时间。

## 20. 第一架次应做什么，而不应做什么

第一架次只验证基本飞行，不执行任务，不开视觉闭环，不做 12 m/s，不投瓶，不自动调参。准备工作必须由能够稳定操纵该机的飞手确认。

起飞前台架已经验证所有传感器与电机方向；实际离地后检查姿态能否稳定、油门与高度是否可控、是否有明显振荡或异响。出现快速振荡、方向异常、严重掉高、异常偏航等就按预先方案中止，不在空中试一串未知增益。

一个合理的递进是：基础姿态可控→AltHold 可控→定位健康时 Loiter→日志检查机械和滤波→基础整定→AutoTune 或 QuickTune→外环和输入整形→载荷包络→任务控制。

官方流程强调先让飞机基本可飞、评估机体、处理滤波，再进入自动整定。新手不应独立完成带桨的第一架次；教程可以教清原理和步骤，但不能替代现场飞手的即时判断。[S02](#s02)[S29](#s29)[S30](#s30)

## 21. 串口、USB、I²C、CAN：从电气层开始排查

先问“是什么电气接口”，再问“跑什么协议”。USB、TTL UART、CAN 是不同物理接口；MAVLink、UBX、RTCM、DroneCAN 是不同的数据格式或协议。

| 接口 | 典型连接 | 最常见错误 |
|---|---|---|
| TTL UART | TELEM、部分 GNSS | TX/RX 未交叉、无公共地、误用 RS-232 电平 |
| USB | PC/NUC 与飞控 | 充电线、端口被占用、线材/接头震动 |
| I²C | 部分外置罗盘 | 拉线过长、地址冲突、供电不符、把 SDA/SCL 当 UART |
| CAN | DroneCAN GNSS、ESC、电源 | H/L 接反、缺终端、总线速率/驱动不对 |

UART 最小连接一般是飞控 TX→设备 RX、飞控 RX←设备 TX、共同信号参考地。设备供电另按硬件说明处理，不能默认把电源正极也连在一起。需要 RTS/CTS 时，线束和两端配置都必须支持，不能只打开参数。

`SERIALn_PROTOCOL` 指协议；`SERIALn_BAUD` 指对应 UART 速率。常见 ArduPilot 枚举中 57 表示 57600、115 表示 115200，**不是 57 baud 或 115 baud**。本文出现的枚举是阅读示例，实际仍应在对应版本参数帮助中确认。[S31](#s31)

CAN 需先启用实际物理总线对应驱动，再选择 DroneCAN 协议。节点还可能有自己的固件、节点 ID 和参数。通常 CAN 线两端需要终端电阻；断电后约 60 Ω 可作为两只 120 Ω 并联的线索，但设备内部电路会影响测量解释，不能带电测电阻，也不能只凭此数值证明总线正常。[S32](#s32)[S33](#s33)

**练习：**画出从“PC 软件”到“RTK 接收机”的每一层：应用→协议→端口→线束→电平→电源。遇到无数据时逐层证明，不从“修改 EKF”开始。

## 22. 推荐的系统分工：遥控、数传、伴随计算机、O4 分开

下面是功能拓扑，不指定尚未知的硬件端口：

```text
地面遥控器 ── 独立RC链路 ── 接收机 ── CUAV
地面Mission Planner ── 数传链路 ── 机载数传 ── CUAV
NUC上的MAVROS ── USB/可靠本地串口 ── CUAV
D435i ── USB ── NUC视觉节点
O4相机/机载端 ── O4数字视频链路 ── 地面显示/判读
RTK基站 ── PC注入/独立修正链路 ── 机载GNSS
```

每条链路承担不同职责。O4 画面清楚不证明 MAVLink 没丢包；地面站连接正常不证明遥控器有效；GNSS 固定解也不证明 D435i 时间对齐。

对于你们的 30 Hz odom，机载本地链路应优先可靠、短路径、高可测性；不要为了省一根线，让高频飞行状态必须先绕地面无线链路再返回机载计算机。

RTCM 可以通过 MAVLink 数传共享发送，也可以用独立修正链路。共享节省硬件但增加拥塞耦合；独立链路减少耦合却增加电源、频率、端口和配置管理。选择依据应是端到端测试，而不是“模块宣传多少公里”。

任何总线都应指定一个明确的数据发送者和参数控制者。多台地面站、MAVROS、自动配置脚本同时修改参数或请求流频率，会出现“自己没改，它却又变了”的问题。[S34](#s34)[S35](#s35)

## 23. SiK 数传：从配对到实际链路验收

这一章**只适用于运行 SiK 固件的数传**，不应把相同设置套到所有 CUAV 无线模块。先确认硬件型号、频段、固件和所在地点允许的发射要求。[S36](#s36)

常见配置流程如下，全部在无桨地面完成：

1. 给地面数传接 USB，给机载数传可靠供电并接好天线；不要让飞控同时被其他串口程序占用。
2. 在地面站的 SiK Radio 配置页面选择地面模块 COM 口并读取 Local Settings。
3. 确认无线连接后读取 Remote Settings；读不到远端时先检查供电、天线、匹配参数与距离。
4. 按该型号要求设置匹配的网络 ID、空中速率、频率范围、纠错/链路选项，再写入并读回。
5. 分别确认地面和机载模块的串口速率与各自接入设备一致；飞控对应 SERIAL 端口选择 MAVLink 协议。
6. 退出数传配置页，再建立正常 MAVLink 连接。观察消息、参数读取、丢包和 RSSI 类指标。

**串口波特率与空中速率不是一回事。**高串口速率不能突破无线链路吞吐；两侧 UART 是否必须同值由设备工作方式决定，但每一侧都必须与其直连设备匹配。

网络 ID 区分链路，不等于加密，也不能消除同频干扰。两队比赛时仍要做频谱/信道协调，遵守场地与当地要求，不在现场靠非法增加功率解决问题。

验收应依次测试：近距离静态→人员和设备工作时→预期最差方向与距离→同时加入 RTCM 与实际消息流。小天线贴电池、金属机架遮挡、极化不一致、两端放太近造成接收饱和，都可能使“桌面测试”与飞行结果完全不同。[S36](#s36)[S37](#s37)

## 24. CUAV 专用数传、网络数传和供电问题

CUAV 品牌下不同数传可能使用透明串口、厂商私有无线协议、网络接口或不同的配置工具。**本文未收到具体型号，所以不虚构统一的“CUAV 数传默认密码/波特率/无线 ID”。**拿到型号后应先读对应手册，并填写附录中的端口记录表。

所有型号共通的配置核对项是：输入电压与峰值电流、逻辑接口、串口模式、UART 波特率、是否透明传输、半双工/全双工行为、空中吞吐、网络端口、天线频段、加密配对、固件版本和参数保存方式。

对带网络接口的设备，再核对 IP、子网、UDP/TCP、监听/发送端、系统防火墙和单向/双向 NAT 行为。能 ping 通仅证明部分网络路径，不证明 MAVLink 目标系统、端口和消息路由正确。

高功率数传不应直接假定由飞控 TELEM 电源脚供电。不同 CUAV 板的外设口电流能力不同；必要时使用匹配的独立稳压电源，信号接地方案按厂商电路要求。飞控偶发重启、GNSS 丢失或 USB 重连，要同时检查这一路供电。[S38](#s38)

现场排障时先缩小到一对数传、一个地面站、一块飞控。最小系统稳定后再加入 NUC、RTK 和 O4。对未识别型号的软件指令、恢复出厂快捷键、固件刷写方法，不凭其他品牌经验操作。

## 25. 带宽预算、30 Hz 导航流与消息率争用

8N1 UART 的理想有效字节率近似 `baud/10`。115200 baud 对应约 11520 byte/s，这还没有扣除协议开销、重传、队列和无线调度。

先按实测或估计的**完整链路帧**做预算。例如若某类完整帧按 60 byte 估计，30 Hz 就需要 1800 byte/s；同时三类便是 5400 byte/s，再加心跳、状态、参数、RTCM 和 ACK。这里的 60 byte 只是教学假设，不是所有 MAVLink 消息的长度。

MAVLink 消息率有多种来源：默认流组、`SRx_*`、地面站 REQUEST_DATA_STREAM、逐消息 `MAV_CMD_SET_MESSAGE_INTERVAL` 等。`SERIAL2` 不应未经核对直接对应 `SR2_*`；SERIAL 编号描述物理逻辑串口，SR 实例和 MAVLink 通道映射还需看固件实际连接。[S31](#s31)[S39](#s39)

`MAV_CMD_SET_MESSAGE_INTERVAL` 使用消息 ID 和以微秒表示的间隔；命令被 ACK 接受仍不意味着已经稳定达到目标频率。必须观察消息到达间隔、长尾和丢帧，特别是在解锁、任务启动、RTCM 注入和日志下载期间。

【源码事实】你们的 `/cuadc/nav30_ready` 由外部节点提供，v11 还要求视觉时刻能被间隔不大于约 50 ms 的 odom 样本夹住。**平均 30 Hz 不排除偶尔 100 ms 的空洞。**航点控制 20 Hz、odom 30 Hz、GNSS 更新率、IMU 采样率、飞控主循环频率是不同层级。[P1](#p1)

建议记录：平均频率、中位间隔、95/99 分位间隔、最大间隔、超过 50 ms 的数量及出现时的其他活动。先查链路和队列，再怀疑 GNSS；不要把 GPS 输出频率改成 30 Hz 当作 NAV30 的修复。

## 26. MAVLink 系统 ID、路由、连接独占与信息安全

同一 MAVLink 网络中的设备通过 system/component 等标识区分。两队飞机、两台地面站或多个路由器混在同一广播网络，可能出现错误绑定、重复消息和状态串线。

一根串口原则上交给一个主程序管理，再通过明确路由转发给需要的程序。Mission Planner、MAVROS、串口监视器直接抢同一个设备，可能造成无法打开或数据被拆分读取。重启程序只能暂时改变抢占顺序，不能解决架构问题。[S35](#s35)

如果使用 mavlink-router 或 MAVProxy，需要画出每个输入/输出端点，防止一个包经多条路径重新回到原点。重复心跳和消息会污染带宽统计，甚至让“某个进程已经死了”仍被其他发送者的心跳掩盖。

MAVLink2 消息签名可用于认证/抗重放层面的防护，但不等同于加密视频或隐藏数据。无线网络 ID 更不是访问控制。重要的是只允许预期终端连接，妥善保存密钥，不把 NTRIP 密码和飞控网络凭据提交到公开仓库。[S40](#s40)

**只读检查示例（Linux，不启动飞行）：**

```bash
ls -l /dev/serial/by-id/
# 将下面设备替换为已核对的实际节点
lsof /dev/ttyACM0
# 仅查看，不根据示例盲目结束系统服务
ros2 topic hz /mavros/local_position/odom
ros2 topic echo /mavros/state --once
```

这些命令只能证明局部状态。权限错误应按系统和设备所有者配置解决，不把全局 `chmod 777` 当永久办法。

## 27. GNSS 基础：3D Fix、Float、Fixed 分别说明什么

卫星接收机的位置解有不同质量状态。常见 MAVLink GPS 状态中，3D Fix、RTK Float、RTK Fixed 是不同枚举；“Fixed”通常指载波相位整周模糊度固定解，不是说飞机被固定在空间中。[S41](#s41)

| 指标 | 说明什么 | 不能单独证明什么 |
|---|---|---|
| 卫星数量 | 当前参与/可见程度的一部分 | 几何一定好、没有多路径 |
| HDOP | 几何相关的精度稀释指标 | 真实误差等于这个数值的米数 |
| hAcc/vAcc | 接收机给出的精度估计 | 独立地面真值误差 |
| RTK Fixed | 模糊度解状态 | EKF 健康、罗盘正确、落点合格 |
| 修正龄期 | 最近有效修正的新鲜程度 | 基站坐标正确、星座消息齐全 |
| EKF 状态 | 融合估计是否满足当前逻辑 | 每个传感器单独完美 |

GNSS 天线需要开阔天空视野、适当的地板/安装方式和牢固支架。钢结构、墙边、树下和 O4/数传等射频设备的供电或布局干扰，会影响结果。不能把天线移到一个更好看的位置后忘记更新外参。

室内通常不具备正常 GNSS/RTK 使用条件。室内出现 EKF 或 GPS PreArm 拒绝并不需要关闭安全检查“解决”；室内测试应使用隔离仿真或已明确设计的非 GNSS 导航方案。

## 28. RTK 的两种“基站”：固定地面基站与机载移动基线

**固定基线 RTK 定位**：地面基站观察卫星，发送修正信息；机载 rover 利用修正求更高精度位置。**GPS for Yaw / moving baseline**：两个机载天线的相对基线用于估计航向。二者可以同时存在，但不是同一功能。[S42](#s42)[S43](#s43)

```text
固定基站定位：
已知或测定坐标的地面天线 → RTCM → 机载 rover → 位置

移动基线航向：
机载天线A ⇄ 基线解算/修正 ⇄ 机载天线B → 航向
```

只有一个 RTK rover，不会因此自动获得静止航向。飞机静止时的航向仍可能来自罗盘、双天线系统或其他被明确配置的源。“有两个 GNSS 插口”也不代表两块任意 GPS 就能组成航向系统。

固定基站的坐标误差可能表现为整套解的共同偏移。相对同一局部基准的短时定位仍可能很好，但地图绝对位置和跨场次复现会受影响。移动基站、换修正源或在飞行中重新确定基站坐标，可能导致不连续，不应在任务中随意进行。

本文不预设你们使用的是哪一款 CUAV C-RTK 或 ZED-F9P 配置。C-RTK 系列不同型号的定位/航向能力、接口与固件配置方法应分别确认。[S44](#s44)[S45](#s45)

## 29. 固定 RTK 基站：从安装到坐标确定

基站先有稳定的安装，再谈精度。选择开阔环境、稳定三脚架、明确天线参考点，不在金属车顶随意挪动后继续使用旧坐标。记录天线型号、序列号、安装点、天线高的定义和坐标来源。

两种常见基站模式：

| 模式 | 用途 | 风险 |
|---|---|---|
| Survey-in | 在未知点自主统计得到基站位置 | 通过时间/估计精度门槛不等于获得测量级绝对坐标 |
| Fixed position | 输入已有可靠坐标，重复使用固定站点 | 坐标基准、经纬度顺序、天线位置或高度填错 |

不要把“设置 60 s、某个 accuracy threshold”写成所有地点的通用精度保证。时间只反映收集过程；现场多路径和坐标基准不会因等一分钟自动消失。

基站页面显示的**survey complete**、串口有数据、RTCM 已发送、机载 rover 收到、rover 已 Fixed 是五个不同节点。排查时逐个确认。独立基站 USB 被别的软件占用，也会导致地面站注入失败。

保存固定点之前确认设备确实在该位置；重新使用保存坐标时，天线必须回到同一参考位置，且高度定义一致。地面海拔、椭球高、天线杆长度不是一个量，不能直接互换。[S42](#s42)[S46](#s46)

**阶段实践 D：**制作基站卡片，写清站点坐标来源、天线高参考面、日期、修正格式、允许使用的固定安装位置。没有这些元数据的“基地坐标.txt”不作为可信站点记录。

## 30. 机载 RTK rover：UART 与 DroneCAN 两条配置路线

### UART 路线

确认 GNSS 供电与协议后接入实际 GPS/UART 端口；在飞控对应 SERIAL 端口选择 GPS 协议，设置接收机驱动类型和自动配置策略。部分版本用 `GPS_TYPE`，较新配置常见 `GPS1_TYPE`；应以实际参数列表为准。

若接收机由飞控自动配置，不要同时让外部工具反复改串口速率和输出消息；若采用手动接收机配置，应保存其内部配置，并清楚飞控是否会在重启时覆盖。**飞控参数保存不等于 GNSS 接收机内部配置已保存。**

### DroneCAN 路线

确认是 DroneCAN 设备而不是“插头长得像 CAN 的其他协议”。启用物理 CAN 驱动与 DroneCAN，读取节点、设备 ID、固件和 GNSS 实例，确认每次重启分配关系一致。使用双 GNSS 时更要避免两个实例互换而参数外参仍按旧编号解释。[S32](#s32)[S33](#s33)

两条路线都必须检查：位置更新、卫星/解类型、精度估计、速度、RTCM 到达情况、重启后的配置、接收机供电和天线连接。不能只看罗盘正常就判断同一线束上的 GNSS 一定正常。

旧 C-RTK 文档可能基于早期 ArduCopter 版本，功能枚举和菜单不能直接套给 4.7。先确认型号和实际驱动选项，再使用该型号手册的接线与操作步骤。[S44](#s44)

## 31. 通过 Mission Planner 给飞机注入 RTK 修正

标准共享链路形态为：基站→PC→Mission Planner→MAVLink 数传→飞控→机载 GNSS。[S42](#s42)[S47](#s47)

可按以下端到端检查表操作：

1. 地面站先与正确的飞机建立 MAVLink 连接，确认 system ID 和型号。
2. 在 RTK/GPS Inject 页面选择实际基站设备的 COM 口及串口速率；这不是飞机的 COM 口。
3. 完成基站 Survey-in 或载入可信固定坐标。
4. 观察输入数据计数和修正发送计数，不把页面停在“已连接”就结束。
5. 在飞机端观察 GNSS 状态是否从单点/Float 进入 Fixed，记录建立时间和修正中断后的行为。
6. 加入实际任务所需状态流，再重复测试，检查 RTCM 与遥测是否争抢带宽。

RTCM 消息和星座应与基站、rover 能力匹配。F9P 常见的是站点信息、各星座 MSM 观测信息及必要的偏差信息；具体消息清单和输出率按接收机固件手册，不在不知道接收机型号时硬塞一份配置。

若用独立无线电直接向 rover 送 RTCM，必须明确接到哪个接收机输入、那个输入是否允许 RTCM、是否存在第二个注入源。**不要让不同基站的修正流无规则混合。**

关闭地面站、PC 休眠、无线断开都会影响这条修正链路。飞行中若依赖它，应事先测试失去修正后 Fixed→Float/单点及 EKF、状态机的整体行为，而不是期待图传还在就一定安全。

## 32. NTRIP：网络修正不是“插上网就 Fixed”

NTRIP 通常涉及 caster 地址、端口、mountpoint、账号、密码和客户端。部分服务需要客户端发送 GGA 以选择或生成附近虚拟参考站。是否需要 GGA、坐标如何提供、使用哪个 mountpoint，以服务说明为准。[S48](#s48)

```text
修正服务/参考站网络
        ↓ Internet
NTRIP客户端（例如地面PC）
        ↓ RTCM
Mission Planner/MAVLink数传
        ↓
飞控 → rover
```

逐层确认：域名可解析→TCP/协议连接成功→认证成功→正确 mountpoint→持续收到非空修正→注入正确飞机→接收机实际使用。HTTP/认证成功页面不是 RTCM；网络连通也不保证延迟小和服务覆盖合适。

账号密码存放在本机受控配置，文档截图打码，仓库中用占位符。不要把含密码的连接字符串写进公开启动脚本、终端截图和日志。

比赛使用互联网还要考虑手机热点省电、流量耗尽、场地蜂窝拥塞、PC 休眠、网卡切换和服务可用性。能否采用自有固定基站或备份修正路径，应结合赛场要求和已经验证的切换机制；**不在空中临时切换未知基准的修正源。**

**实践：**仅在地面记录 10～20 分钟修正龄期、解类型和数据中断，不移动基站、不启动飞行。统计中断持续时间，比看一次 Fixed 截图更有价值。

## 33. 双天线航向、杆臂与 FRD/FLU 的符号

双天线航向的配置需要：兼容的接收机、正确的 base/rover 角色、已知安装基线方向和长度、所需内部修正链路、正确的 EKF yaw 源。**把两个 RTK 模块都设成普通 GPS，不会自动得到航向。**[S43](#s43)[S45](#s45)

基线不能晃动。两天线若装在柔软支架上，振动会改变真实基线；传感器报告的“精度”也不能替代结构稳定性。

杆臂是传感器相对约定机体参考点的位置。ArduPilot 传感器位置参数通常使用机体前、右、下的 FRD；你们 v11 投放口外参使用前、左、上的 FLU。转换关系为：

\[
[x,y,z]_{FRD}=[x,-y,-z]_{FLU}
\]

例如投放口 `[+0.026,-0.065,-0.32]` FLU 对应 `[+0.026,+0.065,+0.32]` FRD。**这是坐标转换示例，不是要把投放口位置填写到 GPS 杆臂参数。**GPS 参数必须测量天线位置，并核对厂商与固件所约定的机体参考点。[S70](#s70)

双天线航向可以在没有外部固定站修正的情况下工作，是否有绝对位置 Fixed 与是否有有效 moving-baseline yaw 要分别观察。起飞前缓慢改变机头方向，检查航向方向、零偏、180° 反向、遮挡后一致性，再做受控试飞。

你们 field 航线通过起飞时航向定义前方。即使用双天线 yaw，也仍需确认起飞摆放是否平行场地中心线。高质量航向源不能修正“摆歪了起飞”的场地标定错误。[P1](#p1)

## 34. EKF 源、低空高度与参考点

EKF 不是简单把所有传感器取平均。它需要明确的位置、速度、高度和航向来源，并根据模型、噪声与创新检验融合信息。`EK3_SRC1_POSXY/VELXY/POSZ/VELZ/YAW` 等参数表示选择的观测源，实际枚举请在运行版本帮助中读取。[S49](#s49)

对室外 GNSS 飞机，常见设计是水平位置/速度来自 GNSS，姿态由 IMU 等融合，垂向结合气压计与速度观测，航向来自罗盘或已验证的 GNSS yaw。**这只是结构说明，不是一份必须导入的 EKF 源组合。**

低空投放最容易混淆三个高度：

- GNSS 给出的绝对高度及其参考基准。
- EKF 本地 z 与任务锁定 home_z 之差。
- 投放口到当前地面或桶口的实际距离。

v11 的 1.3 m 是基于本地 odom 的机体参考点相对高度，不是飞控自动保证出瓶口距桶口 1.3 m。地面高差、baro 压力误差、天线/IMU/机构杆臂都会影响解释。[P1](#p1)

RTK Fixed 不意味着 GNSS 高度一定适合直接取代全部低空高度观测。加装向下测距仪也需要明确量程、朝向、盲区、表面适应性、延迟与融合/地形用途。不能仅因“更准”就把 `EK3_SRC1_POSZ` 改成另一个源。[S50](#s50)

出现 EKF 源报错，优先核对所选择的传感器是否存在并被实际送入飞控。ROS 里存在一个 `/vision/pose` 话题，不等于飞控收到并融合了外部导航；D435i 做桶识别也不是自动在提供 VIO。

## 35. RTK 的验收：固定解率只是第一项

完整验收应包含静态、动态、遮挡和重启四组测试。下面的时间与阈值是**试验设计示例**，不是官方统一准入标准。

| 试验 | 记录内容 | 能回答的问题 |
|---|---|---|
| 固定地面点静置 | 解类型、修正龄期、hAcc/vAcc、本地位置散布 | 短时重复性与链路连续性 |
| 同一点断电重启 | 新 home、base坐标、局部原点、绝对坐标 | 跨次基准是否一致 |
| 开阔地慢速移动 | 解类型变化、速度、延迟、位置跳变 | 动态连续性 |
| 地面中断修正 | Float/单点出现时间、恢复时间 | 修正链路故障后行为 |
| 开启 O4/数传/舵机 | 与静态基线相比的变化 | 电源、射频或带宽耦合 |

没有独立真值时，应写“散布/重复性”，不要写“绝对误差”。有测量基准时，也要明确它的坐标参考系和误差。

检查“总是 Float”按顺序拆分：基站是否稳定并有效→RTCM 是否持续→正确发给本机→rover 接收协议是否正确→共同星座与信号是否足够→是否有遮挡/多路径→频宽和修正龄期→接收机配置及固件兼容。

检查“Fixed 但漂”则分开看：GNSS 原始定位是否跳、EKF 是否切换/重置、磁航向是否错、飞控是否在跟踪移动 setpoint、基站是否移动、机体和机构参考点是否一致。不要把所有现象都归因于卫星数量。

配套 `rtk_metrics.py` 只分析导出的示例 CSV，报告 Fixed 可用时间、数据空洞和龄期条件，不把它当作自动放飞程序。

## 36. 控制环：先分清自己正在调哪个环

一个有用的简化模型是：

```text
任务轨迹/位置目标
       ↓
位置误差 → 速度目标
       ↓
速度误差 → 加速度/推力方向目标
       ↓
姿态误差 → 角速度目标
       ↓
角速度误差 → 力矩指令
       ↓
混控/控制分配 → 各电机输出
```

真实实现有前馈、限幅、输入整形和耦合处理，不是这张图的简单串接，但它能帮助定位问题。[G06](#g06)[S51](#s51)

最内层角速度环大致可写成：

\[
u=K_P e+K_I\int e\,dt+K_D\frac{de}{dt}+u_{FF}
\]

其中 `e=期望角速度−实际角速度`。P 产生即时纠偏，I 处理持续偏置，D 对变化敏感、可提供阻尼但也放大噪声，FF 根据目标运动提前提供作用。ArduPilot 的具体 D 处理、滤波与限幅应以实际实现为准，不能把这个教学公式当固件逐行定义。

| 参数族 | 主要含义 | 一般不负责 |
|---|---|---|
| `ATC_RAT_RLL/PIT/YAW_*` | 角速度跟踪 | 相机外参、地图坐标 |
| `ATC_ANG_RLL/PIT/YAW_P` | 姿态误差到角速度目标 | GNSS 绝对精度 |
| `ATC_INPUT_TC` 等 | 指令响应形状 | 消除供电或振动故障 |
| `PSC_*` | 位置/速度/垂向控制 | 修复错误电机顺序 |
| `LOIT_*`、`WP_*`/`WPNAV_*` | 模式/轨迹速度和动态限制 | 把飞机无限加速 |
| `INS_*`、各 PID 滤波 | 信号处理 | 创造不存在的传感器信息 |

内环不稳定时不要先猛调外环。外环要求的姿态越激烈，可能越快暴露内环和动力问题。

积分饱和也要理解：当电机已经到上限，继续积累误差不会带来更多推力，反而可能延长恢复。看到大 I 时要问是增益不合理、长期重心偏置，还是输出能力不足。

## 37. 怎样用日志判断“调参不对”

按时间顺序找：目标什么时候变化→实际什么时候跟随→输出是否饱和→传感器是否失真→模式是否改变。先定位起因，再看最后的结果。[S27](#s27)[S30](#s30)

| 观察 | 可能含义 | 还需排除 |
|---|---|---|
| 角速度目标平稳，实际高频噪声大 | IMU噪声、结构振动、控制振荡 | 记录率/绘图混叠 |
| 目标阶跃后超调、来回摆 | 环路阻尼/延迟/增益问题 | 上层目标反复改变 |
| 目标明显领先，输出已贴上限 | 动力或控制分配饱和 | 电池压降、桨问题 |
| 姿态跟踪很好，位置绕圈 | 定位/航向/外环问题 | field坐标方向错误 |
| 释放瞬间高度变化 | 质量突变、机构动作、压力扰动 | 视觉或本地高度坐标跳变 |

常用日志族包括 ATT、RATE、PIDR/PIDP/PIDY、RCOU、CTUN、BAT、VIBE、GPS/GPA、XKF 和各类事件。不同固件的字段名、单位和实例可能变化，先查看 BIN 内 FMT/UNIT/乘数定义或日志工具的字段说明，不把网络截图中的曲线列名照搬。[S28](#s28)

对同一片段同时画期望与实际。只画实际角度曲线，无法区分“飞机不听话”和“上层命令本来就在动”。姿态角小也不一定意味着位置精度高；高频小幅抖动仍可能让图像模糊和电机发热。

比较调参前后时，不仅比较 P 值大小。记录 RMS/分位误差、最大超调、整定时间、持续输出不平衡、热量、电池和载荷。一次良好飞行不能证明整个包络。

## 38. 推力曲线、悬停油门与载荷变化

飞控输出不是天然与推力线性。电机、桨、电调、电池电压和空气条件共同决定推力响应。推力曲线、悬停推力估计及电池补偿会影响垂向控制和控制余量。[S52](#s52)

`MOT_THST_HOVER` 或对应悬停学习功能反映某种条件下的悬停输出估计，不是“只要设成 0.5 就最稳定”。自动学习有条件和时间常数，不能期待投掉一瓶后瞬间完成整套重新辨识。

理想定高、倾角为 θ 时，忽略阻力等因素所需总推力为：

\[
T=mg/\cos\theta
\]

因此高倾角转场需要额外推力余量。空载能快速飞，不代表双瓶满载也能保持高度；低电压时情况可能更差。电机输出饱和后，调整 PID 不能增加硬件最大推力。

**配置包络建议**：记录双瓶、仅 A1、仅 A2、空载的悬停输出与控制分配；记录新电池与允许最低工作电量附近的差异。单瓶左右两种情况都测，因为相同质量可能有不同重心偏置。

官方调参流程强调在较灵敏的配置下建立基础整定，通常涉及较小起飞重量和充分电量；这与任务满载验收不冲突。本文的工程建议是：先按适用官方流程建立稳定基线，再验证所有任务载荷，**不是不加区分地“永远满载 AutoTune”或“空载调完直接比赛”**。[S02](#s02)

## 39. 滤波：为什么应在自动整定前完成

D 项对高频噪声敏感。滤波不当时，QuickTune 可能把噪声引起的控制输出变化当作振荡边界，AutoTune 也可能基于污染的响应得到不合适增益。先改机械，再建立合理滤波，是整个流程的前置条件。[S53](#s53)[S54](#s54)

常见概念：

| 名称 | 作用 | 代价或限制 |
|---|---|---|
| 低通滤波 | 抑制高频部分 | 越低的截止频率通常引入越多相位影响 |
| 固定陷波 | 抑制某段固定频率 | 电机转速变动时可能跟不上 |
| 谐波陷波 | 同时针对基频及选定倍频 | 过多陷波增加复杂性与计算量 |
| RPM 跟踪陷波 | 根据有效转速移动中心频率 | 依赖可靠、正确换算的 RPM |
| FFT 跟踪 | 从传感器频谱识别频率 | 需要合适配置和资源，不能修复传感器裁剪 |

`INS_HNTCH_*` 等描述惯性传感器陷波；`ATC_RAT_*_FLTT/FLTE/FLTD` 描述各控制器输入/误差/导数滤波。名字都带 FILTER 并不代表同一层。[S53](#s53)[S55](#s55)

推荐的验证过程是：安全的基本悬停获取日志→看噪声与转速的对应→选择适用的陷波来源→读取前后频谱并看控制响应→确认 CPU/日志无明显问题→才运行自动整定。

不要把网页给的一组 `FREQ/BW/ATT/HMNCS` 不经动力参数核对导入。也不要只看滤后曲线漂亮就继续提高带宽；滤波延迟、控制输出和电机温度一起看。

脚本里的 `QUIK_AUTO_FILTER=1` 只按 INS_GYRO_FILTER 设置部分 PID 滤波，不会替你完成整个动态陷波设计。它可能改动刚刚手动验证过的 FLTT/FLTD，因此要在执行前决定由谁管理滤波，并审阅调参后的差异。[G02](#g02)

## 40. 手动初调：目标是得到可安全辨识的基线

手动初调不等于随机旋转滑块。它要在机体、方向、供电、定位及初始滤波可信的前提下，通过小范围、单因素的改动让飞机基本可飞，给自动整定提供起点。[S51](#s51)

对新手，优先使用与实际桨径、动力和机架匹配的官方初始设置流程，在有经验飞手监督下验证。不要从完全无法悬停的飞机直接启动 QuickTune，因为脚本仍要实际飞行并逐渐改变增益。

每次只提出一个可检验假设。例如“释放摇杆后明显低频回摆，角速度跟踪有超调，输出未饱和，可能需要调整阻尼”；然后依据对应版本调参指导作小范围变更，试飞、记录、比较。不能从“感觉慢”直接得出 P 应加倍。

保守的停止条件应预先定义：振荡增强、异响、电机快速升温、异常偏航、输出贴限、定位质量下降、进入边界或电量不足。出现这些先终止实验，再分析，不在同一次飞行中继续盲试。

本文不提供任意机型的 P/I/D 数值，因为缺少实机动力、惯量、滤波、采样条件与日志。你们真正应该形成的是“何时该改哪一类参数，以及怎样证明改动有效”的能力。

## 41. 三种自动调参：必须先选对名字

| 项目 | ArduCopter 内置 AutoTune | 官方 Lua VTOL-quicktune | 内置 C++ QuickTune（含该功能的构建） |
|---|---|---|---|
| 主要入口 | AUTOTUNE 模式/辅助功能 | SD 卡 Lua applet | 固件内的 AP_Quicktune |
| 参数前缀 | `AUTOTUNE_` | `QUIK_` | `QWIK_` |
| 常见控制 | AutoTune 辅助功能，编号17 | Scripting 功能，默认300 | QuickTune 辅助功能，编号181 |
| 行为特点 | 主动施加测试动作，识别响应 | 悬停中逐渐寻找角速度环增益边界 | 与 Lua 相关但实现和保护有差异 |
| 保存主流程 | 接受后保持相应状态，落地上锁（disarm）时保存 | **落地前 HIGH 保存，确认 saved** | 按对应版本 QWIK 流程 |
| 核心限制 | 基本可飞，需试验空域 | 基本可飞、滤波健康、脚本 API 匹配 | 固件必须实际编入并支持当前模式 |

辅助功能的枚举以实际固件为准，不因表格出现了数字就省略开关测试。[S23](#s23)[G02](#g02)[G03](#g03)[G05](#g05)

**三者不能同时运行。**Lua 脚本和 AutoTune 同时写同一组 ATC 参数，会让各自的“原始值”“测试值”“保存值”失去清晰意义。

不要把 Plane 固定翼 AutoTune、传统直升机 AutoTune 和多旋翼 AutoTune 的参数表混用。它们可能有相同名称，但识别过程、轴定义和适用条件不同。

对你们的 CUADC，可以把 QuickTune 理解为一种建立/改善角速度环基础整定的工具，AutoTune 用于进一步的动态识别；**并非每架飞机都必须连续跑两种，最终选择以适用流程和验收结果为准**。不是“两种都点过”才叫调好了。

## 42. 内置 AutoTune：准备、参数与版本差异

AutoTune 会真实地改变控制行为并主动施加测试运动。所需空间由机型、风、导航质量和试验响应决定，不能沿用投放时 1.3 m 的低空高度。选择开阔、安全、风较平稳的试验条件，并安排飞手随时中止。[G03](#g03)

运行前确认：基本 AltHold 可控，定位模式使用时 GNSS/航向健康；机械无明显摆动，松散云台和载荷问题已解决；滤波已验证；电池余量足够；原参数已导出；AutoTune 的开启/退出开关已无桨核对；ROS 自动任务、其他调参脚本未运行。

固定版本 `Copter-4.7.1` 的 `AC_AutoTune_Multi.cpp` 显示：

| 参数 | 该源码默认值 | 含义与注意 |
|---|---:|---|
| `AUTOTUNE_AXES` | 7 | bit0 Roll、bit1 Pitch、bit2 Yaw、bit3 YawD |
| `AUTOTUNE_AGGR` | 0.075 | 用于 D 项识别的回弹判据，不是航速 |
| `AUTOTUNE_MIN_D` | 0.0005 | D 的下限，不应为掩盖噪声盲调 |
| `AUTOTUNE_GMBK` | 0.25 | 对辨识结果作增益回退的比例，版本相关 |

**不要把网页或旧教程的 AGGR 默认 0.1 当成所有固件事实。**本文明确引用该固定版本的 0.075；实机读回优先，已保存参数也可能不同于编译默认值。[G03](#g03)

AXES 是位掩码：3 表示 Roll+Pitch，7 表示 Roll+Pitch+Yaw，15 还包括 YawD；YawD 并不是飞机多了第四个几何旋转轴。是否调 yaw D 要结合机架、噪声和实际版本能力，不能默认“选得越多越好”。

AGGR 较小不等于所有条件下必然更安全。它改变识别判据，噪声和响应也影响结果。先使用对应流程，再依据日志和版本说明调整，不为了“保守”把它设到范围外。

## 43. 内置 AutoTune：完整的执行、试飞与保存流程

以下使用辅助开关方式描述，具体模式名称和保存细节必须与运行固件一致。该流程与固定版本源码头部的操作说明一致，官方页面也给出了对应流程。[G03](#g03)[S68](#s68)

**起飞前：**保存原参数；开关处于关闭 AutoTune 的位置；机体、失效保护、场地、电量和飞手准备全部完成。

**建立悬停：**使用已经验证的控制方式起飞，进入合适的 AltHold 或官方支持的定位辅助入口，在足够空间内稳定。不要让状态机同时发送任务位置目标。

**开始整定：**启用 AutoTune。飞机会进行一系列测试动作，地面站报告轴和阶段。飞手以安全为最高优先级，不追求一口气完成全部轴。

**重新定位：**源码说明在飞手操作重新定位及测试间隔使用原增益；摇杆释放后继续。该行为不能套到 Lua QuickTune，后者见第 47 章。

**结束并比较：**完成整定后，按对应模式/辅助开关方式切出再切回，测试新增益；必要时回到原增益比较。不要因为出现成功消息就立即认定适用于所有载荷。

**接受结果：**对本章普通辅助开关流程，保持 AutoTune 接受/测试状态，受控落地，并在该状态下 disarm，使结果永久保存。随后导出参数、重启读回，再与前值比较。

**拒绝结果：**落地上锁前退出 AutoTune、恢复原增益；确认没有保存新值。任何异常先以安全结束飞行为主，回到地面后用备份核对实际参数，不在空中为争取保存而冒险。

### 为什么“我调完了，重启后又变回去”

整定完成、试用新值、写入持久存储是三个事件。你可能整定完成后切到普通 LAND/RTL 或关闭辅助开关，再落地上锁，结果并没有按接受路径保存。不同版本还可能支持 `AUTOTUNE_TEST_GAINS` 等额外机制；没有核对该版本之前，不把它与本章普通流程混为一谈。

### 不要照搬给 Lua

内置 AutoTune 的接受路径与 Lua QuickTune **落地前切 HIGH、看到 saved** 的路径不同。把两套步骤混在一起，是丢失整定结果的常见原因。

## 44. AutoTune 卡住、失败或效果不佳怎么办

不要把每次不能完成都解释为“需要更激进”。先按下列证据定位：

| 现象 | 检查证据 | 处理方向 |
|---|---|---|
| 一直等待，不开始动作 | RC 是否真正回中、模式、入口条件、消息 | 修复入口/操作条件 |
| 反复测试某轴 | 噪声、风、结构摆动、响应一致性 | 改善实验条件与基础滤波 |
| 达到限值或终止 | ATUN/ATDE、PID响应、输出余量 | 判断识别是否有效，不直接抬限值 |
| 位置漂得很远 | 使用模式、定位与航向、风 | 中止并恢复位置，不赌剩余几次测试 |
| 整定后电机发热 | 高频输出、D、滤波和电机状态 | 回退，分析噪声与输出 |
| 手动很灵敏但任务不稳定 | 上层目标抖动、外环、输入整形 | 不把手感当任务验收 |
| 重启后参数未保留 | 保存分支、实机读回、日志 | 按持久化流程重新核对 |

回退不一定是全部重做。若某次只改变一个轴或一组滤波，应通过参数差异明确恢复范围；若版本、校准或机架配置也被改动，则需要完整复核。不要随便把两次整定中“看起来大的 P、小的 D”拼起来。

AutoTune 产生的是候选整定，不是无人值守飞行的许可证。通过小幅阶跃/缓和姿态动作、定位悬停、任务转场、载荷变更和落地测试，才形成你们自己的验收证据。

## 45. GitHub 上的悬停 Lua 自动调参：确认脚本，再安装

本文重点研究的是 **ArduPilot 官方仓库的 `libraries/AP_Scripting/applets/VTOL-quicktune.lua`**，不是名称类似的任意论坛附件或私人修改版。[G02](#g02)

本文查阅固定提交：

```text
2e414af057582b2190d95c8d9e44845e06c8ca57
```

对应源码的 Git blob 标识：

```text
3a1d78e81c6090449e0f08b70c64931708e9ff92
```

前者用于固定仓库版本，后者是 Git 内容对象标识；**它不是本教程在本地计算的 SHA256**。附录 H 提供可点击的固定源码和配套说明入口。[G02](#g02)[G04](#g04)

### 安装前四项检查

第一，实际 CUAV 固件是否包含 Lua scripting。H7 等硬件能力并不自动保证每个自定义构建都编入所有功能。

第二，当前脚本用到的 API 和参数是否存在，例如 `ATC_RAT_RLL_SMAX`、`rc:get_aux_cached()`、`AC_AttitudeControl:get_rpy_srate()` 和姿态误差 API。**master 脚本不能天然保证兼容旧固件。**

第三，SD 卡路径和文件内容正确，保存的是 Raw Lua 文本，不是 GitHub 网页 HTML；避免 `.lua.txt`、同名副本和多个版本同时加载。

第四，飞控内存与脚本堆足够，但不要盲目把 `SCR_HEAP_SIZE` 调得非常大挤占其他功能。若构建缺绑定，增大堆不能修复不存在的函数。[S56](#s56)

### 地面安装步骤

拆桨并支撑载荷，备份全参数和 SD 卡脚本。启用 `SCR_ENABLE`，按要求重启；把经核对的文件放到 SD 卡的 `APM/scripts/`，或使用支持的 MAVFTP 方式上传到相同目录。重新启动后读取 Messages，确认脚本正确识别 multicopter、没有缺参数/缺函数/内存错误。刷新参数列表，查看是否出现 `QUIK_*`。

这一步只证明脚本已加载。**不要为验证安装而在台架开启调参，更不要为消除 Must be flying 报错拆掉保护条件。**

建议先在使用相同固件版本与脚本的隔离 SITL 中练习开关状态、参数保存和异常处理。SITL 不能证明真实机架动力稳定，但能减少操作与版本理解错误。

## 46. Lua QuickTune 的 15 个参数逐项解释

下表依据上章固定 Lua 源码。它的配套 `.md` 还残留“增加 7 个参数”的旧描述；本表不据此删掉实际存在的参数。[G02](#g02)[G04](#g04)

| 参数 | 固定源码默认 | 教学解释 |
|---|---:|---|
| `QUIK_ENABLE` | 0 | 是否执行更新逻辑；**不是可靠的空中回退按钮** |
| `QUIK_AXES` | 7 | 位0横滚、位1俯仰、位2偏航；3只调横滚和俯仰 |
| `QUIK_DOUBLE_TIME` | 10 s | 增益按指数增长时翻倍所需时间；更长意味着更慢 |
| `QUIK_GAIN_MARGIN` | 60 % | 检测到振荡后计划减少的比例；60表示保留40%，还受其他约束 |
| `QUIK_OSC_SMAX` | 5 | 对控制器 slew-rate 指标的判断阈值，不是陀螺角速度门限 |
| `QUIK_YAW_P_MAX` | 0.5 | yaw P 的上界 |
| `QUIK_YAW_D_MAX` | 0.01 | yaw D 的上界 |
| `QUIK_RP_PI_RATIO` | 1.0 | 在相应条件成立时，roll/pitch 的 I=P/比例 |
| `QUIK_Y_PI_RATIO` | 10 | 在相应条件成立时，yaw 的 I=P/10 |
| `QUIK_AUTO_FILTER` | 1 | 是否按 INS_GYRO_FILTER 改部分 PID 滤波 |
| `QUIK_AUTO_SAVE` | 0 s | 0表示不自动保存；非零是在完成后等待再保存 |
| `QUIK_RC_FUNC` | 300 | 读取哪个辅助功能缓存，不是 RC 通道号 |
| `QUIK_MAX_REDUCE` | 20 % | 限制相对初始基线的最大增益降低量 |
| `QUIK_OPTIONS` | 0 | 位0启用两段开关行为 |
| `QUIK_ANGLE_MAX` | 10° | 目标姿态与实际姿态的误差角中止阈值，**不是绝对倾角限制** |

### GAIN_MARGIN 和 MAX_REDUCE 为什么看起来矛盾

假设初始 P=0.10，逐渐增加到0.20时检测到振荡。60%的回退计划得到0.08；20%的最大降低限制也允许最低0.08，所以一致。

如果在0.12检测到振荡，60%回退得到0.048，但 MAX_REDUCE=20% 的初始基线下限仍是0.08，最终会受限。两个参数分别约束“相对当前振荡点退多少”和“相对起始增益最多退多少”，不能只看一个。

### AUTO_FILTER 并非自动设计全部滤波器

该源码把当前轴 FLTT、FLTD 设置为 INS_GYRO_FILTER 的一半；yaw FLTE 仅在其低于0或高于8的条件下被设置到8。它不会重做你们的动态陷波，也不保证改变后相位和噪声最优。

### I 项并不总会跟着 P 改

源码在相应 FF 大于0时不做这项耦合；PI ratio 小于1时也不按上述公式更新 I。不要仅根据默认比例推断所有飞机最后的 I 值。

### 不要随意关闭 ANGLE_MAX 保护

将它设为0会关闭该姿态误差检查。若频繁触发，应先检查机体、基础整定、噪声、风和增益增加速率。不能把保护阈值调大当作修复故障。[G02](#g02)

## 47. Lua QuickTune 三段开关：停止、开始、保存

本章是最重要的操作卡。以一个已经确认空闲的 RC7 三段开关举例：地面设置 `RC7_OPTION=300`、`QUIK_RC_FUNC=300`；确认没有与模式、紧急停止、载荷或另一脚本冲突。示例通道不是强制使用 RC7。[G02](#g02)[G04](#g04)

| 开关逻辑值 | 普通三段开关 | 固定源码行为 |
|---|---|---|
| 0 | LOW | 停止整定；有未保存改动时恢复备份；复位中止锁存 |
| 1 | MID | 飞行条件允许时整定/继续 |
| 2 | HIGH | 保存已经改变的参数到持久存储 |

**LOW/MID/HIGH 按飞控实际收到的逻辑状态判断，不按开关外观方向。**

### 完整操作顺序

**地面准备：**备份参数；脚本加载正确；噪声/滤波和基本飞行已验证；只保留一种调参；开关在 LOW；建议初次使用 `QUIK_AUTO_SAVE=0`、普通三段开关，避免未评价就自动保存。

**进入试验悬停：**由飞手在合适空域、足够安全高度建立稳定 Loiter。官方说明以低风悬停为使用场景；试验高度应根据机型、扰动、场地和可恢复空间决定，不沿用任务低空高度。

**开始：**切 MID。观察 `Tuning: starting tune`、当前轴和当前 P/D、输出变化率信息。脚本默认顺序是 RLL_D→RLL_P→PIT_D→PIT_P→YAW_D→YAW_P。

**必要时操作飞行：**飞手始终优先保持安全。该源码检测 roll/pitch/yaw 输入后会延迟继续增益增加，直到输入停止约4秒；但它**没有因这件事自动恢复全部原增益**。不要把“暂停增长”理解成“已经回退”。

**接受：**完成后看到 `Tuning: DONE`，在仍有安全飞行余量的条件下评价响应。认可后切 HIGH，确认 `Tuning: saved`，**在落地之前保存**。然后按受控流程落地、上锁、导出参数、重启读回。

**拒绝或中止：**切 LOW，确认 `Tuning: reverted`（存在未保存更改时）。若脚本异常而不能确认回退，优先使用飞手已经掌握的安全操纵与降落方案；落地后用备份核对和恢复，不能在空中重启飞控作为回退方法。

### 保存的三个陷阱

第一，先 LOW 再 HIGH 会先丢弃未保存结果，不能用来模拟内置 AutoTune 的“低—高测试”。

第二，源码 HIGH 保存分支不要求所有轴 DONE，因此可能保存尚未完成的一组增益。新手应等完成且评价通过后再保存。

第三，已经 HIGH 保存后再 LOW，不能指望回到本次飞行最初的全参数，因为保存操作已经更新了内部备份。需要初始配置时，地面使用真正的外部备份回滚。

### 资料与源码的差异

部分网页描述把摇杆操作与恢复原参数联系起来；本文所固定 Lua 的实际分支只更新时间、暂停后续调参，不执行全参数恢复。控制输出的降增益过渡阶段还可能在暂停判断之前继续完成。因此**以专用 LOW 和回退消息作为操作依据**，而不是把动作相似的内置 AutoTune 习惯带过来。[G02](#g02)[S57](#s57)

## 48. Lua 算法推导：它为什么能在悬停中整定

这不是神经网络，也不在线计算完整机体动力学模型。它在基本可飞的悬停条件下逐步调整增益，用控制输出变化率指标识别接近振荡的区域，然后回退到较保守的水平。[G02](#g02)

### 48.1 每次增长多少

源码的名义更新率为40 Hz，增益翻倍时间为 τ：

\[
m=\exp\left(\frac{\ln2}{40\tau}\right),\quad g_{k+1}=m g_k
\]

τ=10 s 时，连续400次正常增长会使增益约翻倍。实际调参中暂停、状态延迟、异常调度和增益过渡会改变总耗时，所以不能说“六个参数一定60秒完成”。

源码末尾旧注释写10Hz，但函数返回 `1000/UPDATE_RATE_HZ`，常量为40，因此**名义调度是25ms**。Lua 调度不等于飞控内环硬实时频率；受到系统负载影响。[G02](#g02)

### 48.2 先 D 后 P

每个轴先处理 D，再处理 P。增加 P 时在无相应 FF、比例条件允许时关联调整 I。阶段间有约4s等待；增益回落还通过若干步渐变，而不是每次瞬间大跳。

如果降低了某些轴的 D，源码还有联动降低 P 的处理，以降低因此触发 P 振荡的风险。它不是只在参数表里找到一个数字乘倍率。

### 48.3 检测的到底是什么

脚本读取 `AC_AttitudeControl:get_rpy_srate()`，拿当前轴的 slew-rate 指标与 `QUIK_OSC_SMAX` 比较。这个指标来自控制器输出变化，不是直接拿 IMU 的角速度作比较，也不是在 Lua 中进行 FFT。

配套说明中将它写为 Hz 的表述不宜用作严格量纲教学；要按实际固件对 slew-rate 指标的定义理解，不能认为 OSC_SMAX=5 就等于“只检测5Hz振动”。这也解释了为什么传感器噪声和执行器动态都会影响判断。[G02](#g02)[G04](#g04)

### 48.4 它没有替你调什么

该 Lua 不完整辨识角度环 P、最大角加速度、位置环、垂向环、GNSS 噪声、相机时间延迟和风场。调出的增益也不代表真实投放口已经对准。它改善的是任务链路中的一部分。

### 48.5 离线数字练习

初始 D=0.004，振荡时 D=0.020，GAIN_MARGIN=60%，则计划结果为0.008。若原值0.015且 MAX_REDUCE=20%，下限为0.012，最终不会直接降到0.008。这只是算法约束演算，不构成真机 D 建议。

配套 `quicktune_math.py` 可重复这些计算，不包含飞控连接或参数写入。

## 49. 从源码读懂 Lua：变量、API、状态与保护

本文不重新编写可直接上机整定的替代脚本；官方脚本只提供固定版本链接。这里用函数索引帮助新人阅读官方源码。[G02](#g02)

| 函数/对象 | 做什么 | 阅读重点 |
|---|---|---|
| `Parameter()`、`bind_param()` | 绑定已有参数 | 名字不存在时会报错 |
| `param:add_table()` | 创建动态参数表 | KEY冲突与参数数量 |
| `bind_add_param()` | 添加 QUIK 参数并绑定 | 默认值≠实机当前持久值 |
| `get_all_params()` | 记录整定起点 | 在什么时候重新拍快照 |
| `restore_all_params()` | 将改过的参数恢复到快照 | 主要是RAM值，不代替外部备份 |
| `save_all_params()` | 使用 `set_and_save()` 写入 | 同时更新内部备份与标志 |
| `setup_filters()` | 改部分 PID 滤波 | AUTO_FILTER开关影响 |
| `have_pilot_input()` | 读取映射后摇杆/死区 | 不同于模式切换检测 |
| `adjust_gain()` | 改RAM值，可能连带改I | FF和ratio条件 |
| `limit_gain()` | 约束相对初始值的降低量 | 与GAIN_MARGIN分别作用 |
| `update()` | 调参主状态分支 | 判断顺序决定保护语义 |
| `protected_wrapper()` | 用pcall处理运行错误 | 捕获错误不等于恢复全部参数 |

Lua 的 `local` 表示局部变量；`function` 声明函数；表 `{}` 可作数组或字典；`obj:method(x)` 会把对象隐式作为第一个参数；`assert()` 不满足时产生错误；`pcall()` 捕获调用中的异常并返回成功标志和错误信息。

脚本末尾返回“下次要调用的函数”和“延迟毫秒数”，相当于协作式调度。不应写阻塞式长循环抢占资源，也不在高频循环不断写持久参数。

### 安全的第一段 Lua 实践：只读状态

以下完整文件可放在**无桨台架或隔离 SITL**中练习加载。它不修改参数、不发模式、不控制电机/舵机，也不执行 AutoTune。

```lua
-- bench_readonly_status.lua：只读教学，先在无桨台架/SITL验证
local function report()
    local label = arming:is_armed() and "ARMED" or "DISARMED"
    local p = param:get("ATC_RAT_RLL_P")
    local p_text = p and string.format("%.6f", p) or "unavailable"
    gcs:send_text(6, "LAB read-only: " .. label .. " RLL_P=" .. p_text)
end

local function update()
    local ok, err = pcall(report)
    if not ok then
        gcs:send_text(4, "LAB read-only error: " .. tostring(err))
    end
    return update, 2000
end

return update, 2000
```

完成后解释每一行，而不是马上加入 `set_and_save()`。所有被装进 scripts 目录的有效脚本都可能在启动时执行；“只是放在那里”不是可靠的停用方式。比赛部署应移走不需要的教学脚本并核对校验值。

## 50. Lua QuickTune 的异常与回退：比“怎么开始”更重要

### 50.1 `QUIK_ENABLE=0` 为什么不能当空中回退

固定源码一开始检查 ENABLE，小于1就直接返回。这个分支位于恢复原参数逻辑之前，所以可能停止继续整定，**但仍保留已经写进 RAM 的候选增益**。不能把关闭开关名称理解成恢复原参数。

### 50.2 切飞行模式为什么也不能保证停止

这份 Lua 没有像 C++ QuickTune 那样接受 `mode_supports_quicktune` 并据此恢复。官方建议 Loiter 使用，不代表脚本在每次模式切换后都会自动回退。使用专用 LOW 中止，并确认消息。

### 50.3 `pcall` 捕获错误并不自动撤销前面写入

外层捕获错误后发送 Internal Error，并延迟重试；它没有在异常处理分支中统一恢复参数。若错误发生在部分参数已改之后，物理飞机可能继续使用部分改动。此时飞手应按预先方案结束试验，落地后比较全参数。

### 50.4 缺 API、参数表冲突和内存问题

| 报错/现象 | 可能原因 | 安全处理 |
|---|---|---|
| 无 QUIK 参数 | 脚本未加载、目录/扩展名不对、功能未编入 | 无桨检查脚本内容与构建 |
| `could not find ...` | 脚本依赖的参数在该固件不存在 | 核对匹配版本，不删除断言硬跑 |
| `attempt to call ... nil` | Lua binding/API 不兼容 | 使用已验证组合或相同版本SITL验证 |
| `could not add param table` | 动态表KEY冲突或资源问题 | 移除重复/冲突脚本后地面重启 |
| `Must be flying to tune` | 不是armed+likely_flying，或开关太早 | 保持台架安全，不规避此条件 |
| 姿态误差 ABORTING | 实际与目标姿态误差超过保护 | 先终止，查动态与噪声 |
| 地面红色 loaded 消息 | 该源码用很高severity发送部分加载文本 | 读消息正文，不只看颜色 |
| 持续 Internal Error | 更新反复失败 | 不继续调参，不假定自动回退 |

### 50.5 校验值与比赛前清理

`SCR_LD_CHECKSUM` 和 `SCR_RUN_CHECKSUM` 可用于起飞前确认脚本集合。相关 `SCR_DEBUG_OPTS` 的生成校验功能按官方说明在地面使用，保留其他位并核对结果；不要遇到校验错误就清零绕过。[S56](#s56)

它们是起飞前检查的一部分，不是脚本运行时永不崩溃的保证。固定版本、参数快照和飞手中止能力仍然需要。

**最终原则：**先 LOW 并确认回退，再在地面停用/删除脚本；不以切 ENABLE、重启 Lua、重启飞控或空中上锁来替代受控中止。[G02](#g02)

## 51. 内置 C++ QuickTune：为什么不能照 Lua 参数表配置

较新的固件源码还包含 `AP_Quicktune` 的 C++ 实现。是否可用取决于实际编译配置和机型，必须在实机看到 `QWIK_*` 参数并核对对应文档，不能因为 GitHub 存在文件就认定所有 CUAV 固件都有。[G05](#g05)

固定 `Copter-4.7.1` 源码显示两者有实际差异：

| 项目 | 本文固定Lua | 固定版本C++实现 |
|---|---|---|
| 前缀 | QUIK | QWIK |
| RC控制 | `QUIK_RC_FUNC`，默认300 | 专门辅助功能，按固件核对181 |
| 最大降低名称 | `MAX_REDUCE` | `REDUCE_MAX` |
| OSC_SMAX默认 | 5 | 4 |
| yaw误差滤波上限常量 | 8 | 2 |
| 禁用ENABLE时 | 直接返回 | 有待恢复改动时调用中止 |
| 模式支持检查 | 无相同显式检查 | 有 `mode_supports_quicktune` 分支 |

因此，“关闭 ENABLE 会恢复”“切出支持模式会恢复”等保证不能从 C++ 实现推导回 Lua。本文第 47～50 章明确只描述固定 Lua 文件。

不要把两套同时装/启用用于比较。比较应在独立架次，保留共同基线和清晰参数快照，确认加载的是哪一套。机型不明、功能不在构建中时，不通过新增未知参数名称来假装启用。

## 52. 整定完成后的验收：空载、A1、A2、双瓶

完成自动整定后要做的是验证，不是再无休止地追逐更高增益。建议建立以下矩阵，并逐步推进，不在同一架次叠加多个首次试验。

| 配置 | 要验证的现象 | 特别关注 |
|---|---|---|
| 空载、充足电量 | 基础姿态、加减速、小扰动 | 最灵敏配置是否高频抖 |
| 双瓶、充足电量 | 悬停、转场、低速稳定 | 推力余量、热量、机械摆动 |
| 仅A1 | 同样动作 | 单侧重心、输出分配 |
| 仅A2 | 同样动作 | 与A1对称性是否成立 |
| 双瓶→单瓶→空载 | 有计划的载荷转换 | 高度扰动、姿态恢复、机构干涉 |
| 允许最低电量附近 | 已验证动作的低风险版本 | 压降、控制余量、返航余量 |

输入整形让飞机更柔和，不等于必须降低所有姿态 P。应在稳定内环基础上调整任务目标的速度/加速度/jerk 和适用模式的输入时间常数，减少目标本身的突变。

不要在每次投瓶后动态切换一套未经验证的 PID。固定的一组稳健参数覆盖整个任务包络，往往比复杂、没有验证的在线参数调度更可控。

验收记录应能回答：哪组参数、哪份滤波、哪一台飞机、哪个载荷、哪种环境、什么动作、用什么指标判断、下一步允许做什么。仅有 `Tuning: saved` 截图不能完成这些证明。

## 53. 高度、Loiter 与位置外环：AutoTune 之后还有工作

内置姿态 AutoTune 或 Lua QuickTune 不会自动把低空高度、Loiter 刹车和 GUIDED 位置响应全部整定好。这些要在稳定姿态基础上分别验证。[S03](#s03)[S04](#s04)[S49](#s49)

### 垂向控制

先检查高度估计是否可信，再看控制器。气压计受气流、机体外壳和日照温度影响，GNSS 高度也有不同误差；高度曲线跳动并不一定是飞机真的上下跳。对照视频、测距仪或独立标尺测量，以及垂向速度、加速度和推力。

下列问题有不同处理方向：

- 实际高度稳，但日志高度跳：先查观测与估计。
- 高度目标稳，实际缓慢漂：查高度源、偏差和外环。
- 投瓶瞬间上冲后缓慢恢复：查重量突变、悬停推力、垂向限幅与控制余量。
- 高速段掉高且电机接近饱和：查推力/倾角/电池，不先增加垂向 P。

### Loiter

Loiter 对飞手输入、制动、速度限制有自己的参数。`LOIT_*` 不是所有自主模式通用的速度开关。在 Loiter 调得舒服，不代表外部 GUIDED 连续位置目标也会同样响应。

### 外环调试方法

先用很小、平滑的目标变化观察位置与速度响应，确认无边界风险。比较期望位置、实际位置、期望速度和实际速度；若姿态已经准确跟踪，但位置仍超调，才进一步分析外环和目标动态限制。

4.7 的 `PSC_NE_*`、`PSC_D_*` 与旧版 `PSC_POSXY/VELXY/ACCZ...` 不能只通过名称相似猜增益等价。参照固件迁移及实际单位，不把本章当作全参数转换指导。

## 54. GUIDED、MAVROS 与你们的 v11：飞控必须满足哪些条件

【源码事实】v11 订阅 `/mavros/state`、`/mavros/local_position/odom`、罗盘航向及视觉消息，通过 `/mavros/setpoint_position/local` 发送位置目标，通过 CommandTOL 起降，通过 CommandLong 操作舵机。它不直接计算电机输出。[P1](#p1)

接入顺序应为：飞控独立手动/定位飞行验收→只读 MAVROS 状态→核对位置和姿态坐标→隔离仿真任务→低速小范围真实 GUIDED→任务区域搜索和投放。

必须特别区分以下几点：

**导航流新鲜不等于导航解可靠。** v11 的 odom 新鲜检查主要看数据是否及时到达，不直接等于 RTK Fixed 或 EKF 协方差门限。不能因为有30Hz消息就认为厘米级定位有效。

**收到时间不是硬件采样时间。** 当前 v11 对 odom 使用机载主机接收时刻入历史，视觉也按主机时钟对齐。共同时间域有价值，但无法消除上游传感器和串行传输延迟。[P1](#p1)

**速度字段还要看参考坐标系。** v11 从 odom.twist 计算水平模长和 z 速度。理解它们作为世界水平/垂直速度之前，必须核对实际 MAVROS 版本的消息 frame/child_frame 和发布实现；不能仅凭话题名推断。

**飞控角度与任务航向不是同一配置域。** 修改 AHRS、罗盘优先级或 GNSS yaw 后，任务锁定的初始航向、相机外参和 field 前方都要重新验收。

**任务参数不是飞控参数。** ROS 的 `search_speed_m_s`、`fine_align_alt_m` 与 ArduCopter 的导航速度、姿态和垂向限制共同决定最终行为。v11 的 rescue profile 还会覆盖部分 YAML 值，这不表示飞控 PID 被覆盖。

**脱离 GUIDED 不一定是飞手拨了开关。** 飞控自身 failsafe 也可能改变模式。状态机不得与飞控保护反复争抢模式；需要从日志区分主动接管与飞控保护事件。

## 55. 12 m/s 转场：必须先算加速度与刹车距离

这是对前面对话中高速方案的重要边界说明：**把速度参数写成12，不意味着30m转场就能按3秒完成。**这涉及动力、最大倾角、加速度、jerk、控制延迟和安全空间，而不是 AutoTune 是否跑完。

### 55.1 从12减到0需要多远

忽略jerk、风和控制延迟，恒定制动加速度 a：

\[
d_{stop}=\frac{v^2}{2a}
\]

再计入总反应/跟踪延迟 τ，近似：

\[
d_{required}\ge v\tau+\frac{v^2}{2a}+d_{margin}
\]

这不是最终飞行边界模型，但足以排除明显不可能的安排。

| v=12 m/s，假设a | 理想制动距离，不含额外裕度 | 加0.2s延迟后的距离 |
|---:|---:|---:|
| 2 m/s² | 36 m | 38.4 m |
| 3 m/s² | 24 m | 26.4 m |
| 4 m/s² | 18 m | 20.4 m |

表中加速度仅用于算例，**不是推荐给实机的参数值**。

若从12减到6 m/s，a=3 m/s²时，理想距离为 `(12²−6²)/(2×3)=18m`。所以“侦察区前留1.5m就能减完速”不能仅靠规划点位置保证。

### 55.2 30m的静止到静止，能达到12吗

对对称、加速度受限的理想轨迹，达到峰值v并再停下需要至少 `v²/a` 距离。a=3、v=12时为48m，30m不够；30m段的理想峰值仅 `sqrt(30×3)=9.49m/s`，总时间约 `2sqrt(30/3)=6.32s`，还未计jerk和跟踪误差。

### 55.3 你们原轨迹发生器隐含了什么

【源码推导】v11 `start_segment()` 使用20%加速、60%匀速、20%减速的时间分配，长段设定时长为 `T=L/(0.8v)`，不是根据独立最大加速度求解。[P1](#p1)

由此隐含的加速度约为：

\[
a_{implicit}=\frac{v}{0.2T}=\frac{4v^2}{L}
\]

L=30m、v=12m/s时约19.2m/s²。理想定高所需倾角约 `atan(19.2/9.81)=62.9°`，且需要很大的推力余量。**这不是宣称你们飞机会如此倾斜，而是证明该setpoint轨迹没有凭12m/s这个参数保证物理可实现。**

实际飞控会受到自身限幅、控制和动力约束，跟不上移动目标后仍要补追；`segment_complete()` 还要等实际飞机进到终点半径。因此只把轨迹时长相加得到的全流程时间不能当实飞上限。

### 55.4 建立速度包络的顺序

在足够大且安全的试验区，先低速证明刹车与跟踪，再逐级提高速度；每级记录满载/空载、最差电池状态、实际速度、制动距离、侧向漂移、最低高度、最大倾角和输出饱和。测试不通过就停在已验证级别。

8m宽任务区的软边界不是高速制动安全网。越界后才开始拉回的逻辑不保证飞行器投影从未越出物理边界。正常任务规划、真实飞控围栏、制动前瞻和失效处置需要分层设计。

**AutoTune 的价值是改善合理指令的跟踪，不是让物理制动距离消失。**

## 56. 返航与降落：HOME、EKF原点和接地点

飞控 HOME、EKF 本地原点、ROS 节点锁定的 `home_` 和实际起降标志中心应分别记录。它们常常接近，但不能未经验证认定重合。[S58](#s58)[P1](#p1)

v11 使用自己锁定的 local home 返回，正常/故障返回也不是简单调用固件 RTL。飞控自身失效保护触发 RTL 时，则按它的 HOME、RTL 配置与导航能力工作。需要检查两种返回路径是否都处于允许区域。

降落相关速度、转段高度和地形使用在不同固件版本有改名，见第5章。不要让“返航快”变成“地面附近也高速下降”。还应检查桨下气流、地面反射、测距盲区、脚架触地和翻倒风险。[S59](#s59)

【源码事实】v11 的落地确认不依赖 ExtendedState，而用相对高度、速度与连续时间：实际有效门限约为相对高度绝对值≤0.12m、水平速度≤0.10m/s、垂向速度绝对值≤0.08m/s，持续至少2秒。[P1](#p1)

这是源代码针对场地问题采取的设计，**不是通用的触地传感器**。若起降点地面变化、高度估计偏移或低空悬停恰好满足阈值，纯odom判断仍需风险评估。不能为让程序结束，随意扩大阈值并在未确认触地时强制上锁。

最终停止动力应以实际落地、正确的飞控状态和任务逻辑共同确认。没有着陆反馈时优先保留飞手安全处置能力，而不是让程序通过“任务完成”文本掩盖不确定状态。

## 57. 失效保护：不能只依赖 ROS 状态机

飞控、伴随计算机、RC和地面站可能独立失效。设计保护时要问“谁还能运行、谁还有控制权、它看到的故障是什么”。一个已经崩溃的ROS进程不能可靠地给自己发送返航命令。[S60](#s60)

| 故障 | 检测位置 | 需要验证的处置 |
|---|---|---|
| RC链路丢失 | 接收机/飞控 | 失联标志是否真实，模式/动作是否符合计划 |
| GCS心跳丢失 | 飞控 | 监听的是哪个系统，其他进程是否掩盖故障 |
| NUC任务节点死掉但MAVROS还在 | 独立任务监视机制 | 不能只看MAVROS心跳 |
| GNSS/航向严重不可信 | EKF/飞控 | 不再依赖坏位置做常规RTL |
| RTCM丢失但仍有GNSS | 接收机/质量监视 | 按定位质量和任务阶段降级，不把Float当必然失控 |
| 电池低/严重低 | 电池监视/飞控 | 足够提前量、返航和紧急落地策略 |
| 舵机状态不确定 | 任务节点/机构反馈 | 禁止重复盲投，保护剩余载荷 |
| 超围栏 | 飞控/任务规划 | 制动与返回空间，不能与外部指令争抢 |
| 脚本运行错误 | Lua/地面消息 | 停止调参、稳定着陆、地面核对参数 |

### 围栏不是搜索航线内缩的替代词

飞控围栏可包含以HOME为基准的范围及上传的多边形/圆形包含、排除区域，类型、使能和越界动作需要分别配置。上传任务航点不等于已经上传围栏；配置了围栏列表也要确认实际使能和采用的坐标/高度参考。[S69](#s69)

对CUADC狭长区域，不能用一个很大的HOME圆形围栏就声称已保护两侧边界。也不能把边界恰好贴在人员安全线，期待高速越界触发后瞬间停止。应结合制动距离、定位误差和返航路径设计缓冲区，先在隔离仿真中验证。v11的SEARCH软边界仅覆盖特定任务状态，不代替全任务飞控保护。[P1](#p1)

### RC、GCS与GUIDED超时不是一回事

Radio failsafe 看RC信息；GCS failsafe主要看相应MAVLink心跳；GUIDED目标超时依指令类型和版本处理。某些速度/加速度控制有停止更新后的超时行为，但**不能据此断言连续位置setpoint一停就自动RTL**。[S61](#s61)[S62](#s62)[S04](#s04)

`FS_OPTIONS` 可改变失联时是否继续 AUTO/GUIDED 或继续降落等行为。不要把网上一个位掩码复制给所有任务；逐项读所选位并写进失效矩阵。尤其不要误把与载荷释放有关的失效选项加进普通返航配置。

### 电池保护

低电量与严重低电量可设计不同动作，但需要真实电压/电流监视正确、判据与负载压降合理。仅根据静置电压推算可飞时间不够。高速满载增加电流，可能使电池保护更早出现；关掉保护不是提速办法。[S12](#s12)

### GPS不可用时

不具备可靠水平定位的飞机不能指望普通RTL解决所有问题。是否使用AltHold、Land或经过配置验证的其他机制，应由飞手能力、环境与固件支持共同决定。不要首次在真实比赛中验证死推算返航。

所有失效注入先在L1/L2执行。实际飞行中不要为“测试”突然关闭发射机、断飞控电源或拔线；必须采用单独评估的受控试验方案。

## 58. 常见报错（一）：连接、校准与不能解锁

以下是按机制组织的诊断表。报错文本会随固件有所变化，搜索时应保存原文；本表不是关闭检查的快捷清单。[S05](#s05)

| 报错或现象 | 第一轮检查 | 不要这样处理 |
|---|---|---|
| 找不到COM口 | 数据线、USB供电、驱动、系统设备列表 | 反复刷新未知固件 |
| COM端口被占用 | MP/MAVROS/终端/配置工具是否同时打开 | 多个程序同时重试抢端口 |
| Waiting for heartbeat | 接口、协议、速率、路由、目标ID | 先改姿态PID |
| 参数下载不完整 | 链路质量、其他数据流、多个GCS | 带着未知参数状态起飞 |
| 参数名不存在 | 固件版本、功能是否编入、名称迁移 | 手动创建同名参数假装支持 |
| 参数写完变回去 | 写入ACK、重启要求、脚本/其他客户端覆盖 | 重复提高写入频率 |
| Accels not healthy / inconsistent | 硬件、方向、静止状态、校准、温度 | 关闭全部IMU检查 |
| Gyros not healthy / inconsistent | 上电是否移动、异常IMU、日志 | 让飞机带故障强制解锁 |
| Compass not calibrated / inconsistent | 磁场、设备ID、安装、是否正确重启 | 在钢桌上反复校准 |
| Check mag field / offsets high | 场地磁干扰、线束/供电、校准条件 | 单纯放大阈值 |
| AHRS/EKF not ready | 等待状态、GNSS/航向源、时间与原点 | 仅凭GPS颗数够就强制飞 |
| Need position estimate | 当前模式需要定位而估计不可用 | 在室内关GPS检查飞GUIDED |
| Hardware safety switch | 实物按钮与安全状态、输出掩码 | 永久旁路安全功能 |
| Motor Emergency Stop | 实际RC逻辑值与辅助绑定 | 不查开关就反复上锁解锁 |
| RC not calibrated / failsafe | 接收机协议、端点、失联标志、RCMAP | 用固定RC覆盖掩盖断链 |
| Throttle too high | 输入校准、摇杆位置、反向和映射 | 取消油门门禁 |
| Duplicate Aux Switch Options | 重复绑定及多个开关权限 | 随机删一个不记录 |
| Battery unhealthy / low | 实际电池、监视类型、线束、比例、容量 | 把低压保护全设0 |
| Board voltage异常 | 电源、USB与外部供电、峰值负载 | 当成GPS问题反复重启 |
| Logging failed / no SD | 卡、文件系统、可用空间、写入性能 | 未留日志就开始自动调参 |
| Main loop slow / CPU负荷 | 日志配置、脚本、外设、消息负荷 | 继续增加高频采样 |
| Scripting checksum / out of memory | 实际脚本集合、堆、构建、版本 | 清掉校验或无限增大堆 |

推荐流程：记录完整原文→说明当前试验等级→最近只改变了什么→用最小系统复现→找到原因→恢复检查并重试。若重启后暂时消失，应保留“未定位原因”的状态，不把它计为修复。

## 59. 常见报错（二）：飞起来之后的控制问题

| 现象 | 建议证据链 | 典型处理方向 |
|---|---|---|
| 起飞立即侧翻 | 机架图、逐电机台架记录、HUD方向 | 修正电机/桨/安装方向 |
| 高频抖动、电机尖叫 | 原始gyro、PID输出、D、滤波、结构 | 终止；先机械与噪声 |
| 慢周期晃动 | 姿态目标和实际、外环目标、I项 | 分层找环节，不统一改PID |
| 定点“马桶圈” | 航向真值、位置轨迹、实际倾斜方向 | 先导航/罗盘/外环 |
| 加速时明显掉高 | 电池压降、推力、倾角、输出饱和 | 降低动态要求并查动力 |
| 刹车过头后再拉回 | setpoint速度、实际速度、制动距离 | 改合理轨迹/制动包络 |
| 满载稳、空载抖 | 不同重量时响应、D噪声、电机温度 | 验证最灵敏配置的整定 |
| 空载稳、满载无力 | 输出上限、悬停推力、重心 | 评估动力和控制余量 |
| 只有单瓶时偏航/侧倾 | A1/A2重量位置、输出分配、机构 | 分别验证两种单瓶状态 |
| 投放后大幅上冲 | 释放时间、推力、真实高度、载荷变化 | 垂向与机构时序共同分析 |
| 地面跳动、将落不落 | 地面识别、脚架、地效、下降配置 | 不把低空抖动当纯姿态P问题 |
| AutoTune不开始 | RC死区、模式、入口消息 | 修复输入/模式条件 |
| AutoTune完成未保存 | 开关/模式路径、上锁时状态、参数差异 | 分清完成、测试、保存 |
| QuickTune不开始 | QUIK使能、辅助功能、脚本API、likely_flying | 不删安全条件 |
| QuickTune姿态误差中止 | 目标/实际姿态误差、风、噪声、增益速度 | 不先关闭ANGLE_MAX |
| QuickTune退出仍像新增益 | 是否仅关ENABLE/切模式、是否HIGH保存过 | 依据固定源码回退流程 |
| 控制命令看似迟钝 | 输入整形、姿态限制、输出、上层滤波 | 不只增加P |

带桨异常首先按安全计划结束试验。日志分析是在确保飞行安全之后进行的工作，不是让飞手一边看曲线一边在空中搜索参数。

## 60. 常见报错（三）：RTK、数传、NAV30 与任务问题

| 现象 | 最短诊断路径 |
|---|---|
| 数传Local能读，Remote不能读 | 远端电源→天线→匹配设置→无线距离/干扰→固件 |
| 链路RSSI高但仍丢包 | 空中速率、排队、重传、近距饱和、双向负荷 |
| 一开参数下载，odom就变慢 | 整链带宽预算、请求流冲突、串口与无线吞吐 |
| O4正常但地面站掉线 | O4与MAVLink分属不同链路，不互相证明 |
| 基站survey完成，飞机仍无RTK | RTCM发送→注入目标→GNSS接收端→兼容信号 |
| NTRIP认证成功却没数据 | mountpoint、GGA需求、服务覆盖、真正RTCM内容 |
| 一直Float | 修正龄期、星座/消息、天线环境、基线、接收机配置 |
| Fixed反复掉 | 遮挡、多路径、供电、射频、修正间断及链路拥塞 |
| Fixed但整体航线偏 | 起飞航向、field标定、绝对/局部原点、杆臂 |
| 换天线后航向相反 | moving baseline角色、基线方向、设备实例顺序 |
| CAN GNSS偶尔不见 | 终端、H/L、供电、节点固件/ID、实例重排 |
| `Waiting lock` | 分别看odom、compass、heading、nav30、vision、armed门禁 |
| `HARD_SYNC_REJECT_AFTER_WAIT` | 时间域、真实间隔空洞、消息延迟、接收队列 |
| `VISUAL_FAILSAFE` | 是视觉心跳断还是对齐失败，别直接改GPS率 |
| `Direct release waiting` | 逐字段检查identity/area/geometry/z/速度/姿态 |
| `SEARCH_BOUNDARY_RECOVERY`频发 | 航向/横向标定、超调、实际制动能力，而非只缩航线 |
| 舵机ACK迟到/超时 | 服务链路、输出配置、负载、FC执行状态；物理状态不确定 |
| 到HOME却不上锁 | 真实落地、高度基准、速度、连续确认；不能强制结束 |
| 程序退出但飞机继续保持目标 | 节点退出、MAVROS心跳和GUIDED类型超时分开设计 |

表中带代码字符串的项目来自 v11；其余是工程诊断分类，不是对你们某次未提供日志飞行的既定结论。[P1](#p1)

## 61. 六个完整教学案例：先建立假设，再修改配置

下面都是**教学情境**，不表示已经在你们飞机上确认发生。

### 案例一：飞机在2.2m搜索稳定，1.3m投放总是过不了释放门禁

先看日志是高度不满足、速度不满足，还是视觉/身份问题。若姿态跟踪正常但水平速度持续约0.2m/s，检查目标是否仍在漂动、外环是否过冲、风是否太大；若height_error持续偏常量，检查本地高度参考和地面，而不是优先加垂向I。

实验拆成固定local目标悬停、视觉仅记录、视觉闭环三次。只有第三次变差，则更可能与视觉目标或时延有关。不要用放宽所有释放门禁掩盖信息质量问题。

### 案例二：开了O4之后RTK容易从Fixed掉到Float

地面保持天线位置和基站不变，只切换O4工作状态，记录rover解、供电、修正龄期。若修正龄期没变而GNSS质量变差，查射频/供电/布线；若同时MAVLink流变差，查共享电源或计算/通信负荷。

先通过改变供电路径、物理隔离或线束布置进行有记录的单变量实验，不直接把GPS过滤参数调松。任何器件供电改动先按额定参数设计。

### 案例三：QuickTune完成了，落地后没有新参数

还原开关时序：是否看到DONE？是否在仍飞行时切HIGH并看到saved？是否先LOW再HIGH？是否在保存前落地使likely_flying变false？是否其实运行的是AutoTune或QWIK？

用地面备份和日志确认，不凭界面当前一个P值判断全部参数。不同调参器的保存步骤不同，是本例的关键。

### 案例四：改成12m/s后搜桶效率反而更低

画setpoint与实际轨迹。若到区域时实际速度仍高，或者飞机需要补追和回拉，就不是“视觉识别变慢”这么简单。检查第55章的加速度、入区速度、制动距离和固定航段重启方式。

先改成经过验证的动态包络，在进入搜索区前完成减速，再比较有效覆盖和稳定桶确认时间。只看移动setpoint完成时间会低估真实用时。

### 案例五：两个舵机同时动作时飞控短暂重连

确认是否真正飞控重启、仅USB断连、GNSS单独掉电，还是MAVLink拥塞。对照上电时间、消息和电源波形/测量，检查舵机BEC、共地与回流、堵转峰值。

修复电气问题后重做全部校验；不能通过加长service timeout把飞控掉电伪装成正常慢响应。

### 案例六：第一次飞行航线正常，换场地后整体偏左

先确定“偏左”是平行平移还是角度误差随距离增长。平移更像起飞点/field偏置；距离越远越偏更像航向/场地对齐问题；只在某转弯越界则查制动和轨迹。

RTK基站位置、HOME、起飞机头方向和场地坐标都可能改变。先测量区分，不用PID去补偿场地几何错误。

## 62. 阶段实践：离线工具怎样帮助调飞控

配套压缩包中的工具全部只读取本地文本，不连接串口、网络或飞控，不发送解锁、模式、舵机和参数写入命令。它们帮助新人建立“有数据再判断”的习惯。

| 实践 | 文件 | 学习内容 |
|---|---|---|
| 参数快照与差异 | `tools/param_audit.py` | 文件格式、重复项、位掩码、版本提示 |
| 制动预算 | `tools/braking_budget.py` | 速度、加速度、延迟、轨迹可实现性 |
| 连续稳定门 | `tools/flight_metrics.py` | 时间连续性、坏帧重置、长数据空洞 |
| RTK可用性 | `tools/rtk_metrics.py` | 时间加权、修正龄期、Fixed不等于真值 |
| QuickTune数学 | `tools/quicktune_math.py` | 指数增益、回退比例、基线下限 |
| Lua只读观察 | `lua/bench_readonly_status.lua` | 参数读取、GCS文本、周期回调 |

运行方式以压缩包README为准，例如：

```bash
cd CUADC_飞控_阶段实践与记录模板
python3 -m unittest discover -s tests -v
python3 tools/param_audit.py examples/before.param --compare examples/after.param --family 4.6
python3 tools/braking_budget.py --distance 30 --speed 12 --accel 3 --latency 0.2
python3 tools/flight_metrics.py examples/flight.csv
python3 tools/rtk_metrics.py examples/rtk.csv
python3 tools/quicktune_math.py --initial 0.10 --detected 0.20
```

### 实践1：为什么不能自动“修复参数”

`ARMING_CHECK`的合法组合、输出分配和脚本使能都依赖实际硬件及任务。本工具只提示“需要人工核查”，不把警告自动变为导入文件。示例`.param`为教学数据，**不允许导入飞控**。

### 实践2：稳定0.5秒不是连续10个好点那么简单

假设20Hz采样，出现连续10个合格样本，但中间丢了1秒。按样本数判稳定会错误接受；按真实时间和最大间隔判定会重置。脚本将长空洞视为不能证明连续稳定，不做前向填充。

### 实践3：RTK统计为什么要计入没数据的时间

一段10秒日志，前1秒有Fixed，随后9秒根本没数据，不能说固定解率100%。工具明确分别报告可观测时间、未覆盖时间与整个观测窗口下的条件满足比例。

### 实践4：验证后再喂真实导出数据

CSV是本文定义的统一教学格式，不直接假装支持所有ArduPilot BIN字段。真实日志导出时先确认单位、参考坐标系、时间和传感器实例，再映射列名。工具的通过结果只是所输入数据满足教学条件，不构成起飞或投放许可。

附录 E 嵌入全部 Python 工具源码，主Markdown离开ZIP仍可按文件路径保存使用。测试和合成数据则随ZIP提供。

## 63. 从第一天到比赛放行的阶段验收

不要按“看完第几章”判定学习完成，要按可重复的操作与证据验收。

| 阶段 | 产出 | 通过标准 |
|---|---|---|
| 接手硬件 | 硬件清单、照片、供电/接口图、原参数 | 能区分板型、固件、协议和输出 |
| 静态配置 | 校准记录、无桨电机图、开关表、舵机记录 | 别的队员可以独立复核 |
| 通信与导航 | 数传配置、带宽统计、RTK基站卡 | 重启后可复现，错误能定位到层级 |
| 基础试飞 | BIN、电池/载荷、飞手记录 | 姿态/高度可控、没有未解释异常 |
| 滤波与整定 | 前后参数、频谱/响应、保存验证 | 数据支持改善，没有新增过热/饱和 |
| 任务载荷 | 四种载荷矩阵、转换测试 | 不只空载稳，单瓶左右也验证 |
| 速度包络 | 逐级速度、制动、侧移、最低高度 | 有足够区域和异常余量 |
| 全任务 | 多次完整任务日志、失败原因统计 | 成功条件、物理释放与着陆可核查 |
| 比赛冻结 | 固件、脚本、参数、工作空间归档 | 一键启动可复现，回滚路径明确 |

速度和精度指标由你们的机体、场地和任务定义，不通过教程给一个通用“放飞分数”。比赛版应删除/停用临时调参入口，确认不会误触开启 AutoTune/QuickTune。

当天风、温度、地面、卫星环境、电池或载荷与验收条件明显不同时，重新评估包络；不要把某天通过的高速结果当无条件授权。

## 64. 团队传承：每次调参必须能回答的十个问题

把每架次写成实验，而不是只保留一段“飞得不错”的视频。

1. 当前板型、固件和脚本是哪一版？
2. 飞前参数快照在哪里？
3. 当前载荷、电池、重心和机械结构是什么？
4. 本次只验证哪个假设？
5. 什么观测支持/反驳这个假设？
6. 为什么这次修改属于这个控制层，而不是其他层？
7. 何时中止、谁中止、怎样恢复？
8. 新参数是否真正持久保存且重启读回一致？
9. 哪些载荷/速度/环境已经验证，哪些没有？
10. 下一个队员能否根据记录重现，而不需要猜测？

推荐提交到Git的内容是可公开的配置模板、经过脱敏的参数差异、文档、测试脚本和硬件版本说明。不要上传NTRIP账号密码、无线密钥、未授权场地坐标或含个人信息的材料。

完整参数可以在团队受控仓库保存，但必须与机体身份绑定；公开分享时应明确“不可直接导入其他飞机”。官方Lua脚本使用固定提交链接，记录来源和许可证，不将自己的修改版伪装成官方版本。

**这套工作的终点不是“AutoTune成功”，而是：指定硬件、指定配置、指定环境包络内，飞机能重复完成任务，而且在任务不能继续时有可验证的安全退出路径。**

## 附录 A. 新飞控从开箱到基础放行：可执行的配置工作单

本附录把前文知识重新组织成操作顺序。它是**检查工作单**，不是自动设置全部参数的文件。每个阶段做完都保存快照，不越过未解释的报错。

### A.1 第一次连接前

记录实物标签、硬件修订、序列号和载板型号，拍摄线束未遮挡时的照片。检查外壳固定、SD卡、连接器、减振安装和电源极性。把所有桨取下，投放机构卸载或支撑，断开暂不需要的外设；先用最小系统确认飞控本体。

从官方渠道安装地面站及必要驱动。Windows中确认设备管理器有稳定的设备；Linux中确认对应的`/dev/serial/by-id/`链接。不要把“COM号换了”判断为固件损坏；bootloader和正常固件可能枚举不同设备。[S06](#s06)[S63](#s63)

### A.2 已有固件与空白/其他固件的处理不同

已有ArduCopter时先连接、读取完整版本、导出全参数与日志；不以升级作为排查所有问题的第一步。若确需刷写，使用**与实物板型和硬件修订匹配**的官方固件目标，按地面站指引进入加载过程。[S63](#s63)[S64](#s64)

`.apj`是常见的ArduPilot固件封装，不是参数文件。不能因为一个文件也是H7编译就强制刷给任意H7板。板型、引脚、IMU、IO MCU、存储和供电监测的定义都可能不同。[G10](#g10)

Bootloader更新、DFU恢复、自定义构建属于维护操作，通常不是普通调参步骤。遇到板ID拒绝或加载失败，应先核对型号、端口、线材与厂家说明，不删除校验强刷。自定义固件还要记录被裁掉的功能；少了Lua、某传感器驱动或日志功能，不能靠添加同名参数补出来。[S65](#s65)

刷完后重新读取版本和参数，按版本迁移说明核对重命名与单位，重新执行静态验收。恢复出厂会改变校准、输出和失效保护，不能在“恢复”后跳过配置直接带桨飞行。[S66](#s66)

### A.3 配置顺序与保存点

| 顺序 | 操作 | 留下的证据 | 此时不要做什么 |
|---|---|---|---|
| 1 | 确认板型、固件、默认配置来源 | manifest及原参数 | 导入陌生整机参数 |
| 2 | 机架类型与飞控安装方向 | 参数、实物俯视图 | 用姿态增益修电机次序 |
| 3 | 电源模块类型、测量校准 | 万用表/电流计对照 | 让未知BEC反向供电 |
| 4 | 加速度计、水平校准 | 每个方向的校准结果 | 把倾斜工作台当水平 |
| 5 | 罗盘发现、优先级、方向、校准 | 设备ID和航向检查 | 用偏置参数掩盖强磁干扰 |
| 6 | 遥控校准、模式、辅助开关 | 输入范围和开关表 | 复用危险功能通道 |
| 7 | ESC协议和输出功能 | 每个输出的电气/逻辑图 | 混用同组PWM/DShot |
| 8 | 无桨逐电机检查 | 测试字母、位置、旋向 | 认为测试A天然等于Motor1 |
| 9 | 舵机供电与行程 | 独立供电、支撑载荷测试 | 无桨测试时突然落下重物 |
| 10 | GNSS/RTK和高度源 | 基站卡、位置/航向记录 | 在任务中换基站坐标 |
| 11 | 数传、NUC、O4逐个接入 | 带宽/供电/干扰对照 | 同时让多程序抢串口 |
| 12 | 起飞前检查与故障链验证 | 完整消息、预期动作表 | 关闭检查来换一个绿灯 |
| 13 | 日志设置与读取试验 | 能打开的BIN及字段 | 所有原始流同时开到最高 |
| 14 | 基础试飞、机械与滤波验证 | 第一段悬停日志 | 第一次起飞就自动调参 |
| 15 | 单一种自动整定和保存验证 | 前后参数、整定日志 | 保存后立即高速全任务 |
| 16 | 全载荷、导航和任务验收 | 重复结果与包络 | 以一次成功替代放行 |

### A.4 三个条件明确的串口配置例子

下面是**学习如何填写设置表**的例子。只有在端口映射与设备协议已经确认时，才根据实机参数帮助设置。示例不以`.param`形式提供，避免被误导入。

| 场景前提 | 飞控端要确认 | 对端要确认 | 验证方法 |
|---|---|---|---|
| 某V6X的TELEM1已核实为SERIAL1，接MAVLink2数传 | SERIAL1协议选择MAVLink2；该UART速率匹配机载数传UART；流控与线束一致 | 接收UART参数、空中链路和地面模块参数 | 独立读取版本/状态，加入RTCM后再次统计 |
| 某GPS1已核实为SERIAL3，接UART GNSS | SERIAL3协议选择GPS；接收机驱动与自动配置策略 | 支持的输出协议和速率；设置是否会被飞控覆盖 | GPS数据、实例、重启后配置、Fixed建立过程 |
| NUC通过USB连飞控 | USB对应接口与MAVLink配置；没有其他程序占用 | 稳定by-id路径、MAVROS FCU URL、权限 | 本地状态/odom间隔与断开后的行为 |

USB虚拟串口的波特率字段不应简单当成USB总线物理速度上限；真实UART上的波特率则必须匹配。两种连接方式不能机械套用同一个带宽计算。[S31](#s31)[S08](#s08)

### A.5 CAN配置的逐层核对

先画物理总线：飞控CAN口、线缆长度、分支、终端、每个节点及供电。再核对“物理端口使用哪个驱动实例”和“该驱动使用什么协议”。最后才进入节点发现、节点固件与节点自身参数。[S32](#s32)[S33](#s33)

看到CAN节点不等于已经配置成GPS；看到GPS也不等于其罗盘或移动基线航向都正确。重启后记录设备ID与实例，尤其不要让主备GPS编号变化后沿用另一根天线的杆臂。

设备接入以后记录一份“单独正常”的基线，再把O4、机载计算机和舵机加入。只有组合时才出问题，优先怀疑共用电源、地线、资源、带宽和射频耦合，而不是反复刷接收机。

### A.6 持久化验证的标准动作

地面写参数→读回→导出快照→按要求重启→重新连接→再读回→核对实际功能。需要重启才能生效的功能，在没有重启前不以界面显示判断成功。

数传、GNSS和Lua脚本也可能有独立持久化步骤。明确“保存到谁的存储”。若只是PC软件保存了配置文件，飞控并不一定已经使用；若Lua只调用`set()`，也不等于`set_and_save()`。[S07](#s07)[G02](#g02)

## 附录 B. 参数阅读方法：单位、枚举、位掩码与版本迁移

### B.1 读一个参数必须读六件事

**名字、单位、值类型、适用范围、是否需重启、当前值来源。**当前值可能来自默认值、旧参数迁移、用户持久化、脚本临时改写或自动学习。参数“看起来与默认值不一样”本身不是错误。

数字枚举是一个选项编号；位掩码是多项选择；普通浮点数才通常直接代表物理量。例如`QUIK_RC_FUNC=300`不是第300个接收通道，`QUIK_AXES=3`也不是“调第三个轴”。[G02](#g02)

### B.2 位掩码亲手算一遍

若bit0表示横滚、bit1俯仰、bit2偏航，则各位权分别是1、2、4。

| 需要的轴 | 二进制 | 十进制 |
|---|---|---:|
| 横滚 | 001 | 1 |
| 俯仰 | 010 | 2 |
| 横滚+俯仰 | 011 | 3 |
| 偏航 | 100 | 4 |
| 三轴 | 111 | 7 |

“bit5”对应`1 << 5 = 32`，不是数值5。操作某个位时，不能把整个参数覆盖成32而无意清掉其他已经使用的位。对新手更合适的是地面站的逐项选框，并在写回后核对。[S56](#s56)

位编号含义必须来自该参数自己的说明。`QUIK_AXES`的bit0和`ARMING_CHECK`的bit0没有任何共同含义。

### B.3 单位换算与量纲检查

| 物理量 | 换算例子 | 常见错误 |
|---|---|---|
| 长度 | 120 cm = 1.20 m | 把厘米直接填米 |
| 速度 | 1200 cm/s = 12 m/s | 只改名字没改数值 |
| 加速度 | 300 cm/s² = 3 m/s² | 把速度值当加速度 |
| 角度 | 3000 cdeg = 30° | 把30°写成3000° |
| 角速度 | 9000 cdeg/s = 90°/s | 与rad/s混用 |
| 时间 | 33333 μs ≈ 0.033333 s | MESSAGE_INTERVAL写毫秒 |
| PWM脉宽 | 1500 μs = 1.5 ms | 当作舵机角度或频率 |

ArduCopter源码、MAVLink消息和ROS消息还可能分别使用不同坐标与单位。参数值是米，不代表所有日志字段也一定是米；数据导出工具可能已经应用了缩放。

### B.4 4.7迁移的附加对照

本表用于找到新名字，**不生成迁移文件**。名字和量纲以固定版本与读回元数据复核。[G06](#g06)[G07](#g07)[G08](#g08)

| 旧参数 | 4.7名字 | 主要变化 |
|---|---|---|
| `ATC_SLEW_YAW` | `ATC_RATE_WPY_MAX` | cdeg/s→deg/s |
| `LOIT_ACC_MAX` | `LOIT_ACC_MAX_M` | cm/s²→m/s² |
| `LOIT_BRK_ACCEL` | `LOIT_BRK_ACC_M` | cm/s²→m/s² |
| `LOIT_BRK_JERK` | `LOIT_BRK_JRK_M` | cm/s³→m/s³ |
| `PILOT_TKOFF_ALT` | `PILOT_TKO_ALT_M` | cm→m |
| `RTL_ALT_FINAL` | `RTL_ALT_FINAL_M` | cm→m |
| `RTL_CLIMB_MIN` | `RTL_CLIMB_MIN_M` | cm→m |
| `WPNAV_ACCEL_C` | `WP_ACC_CNR` | cm/s²→m/s² |
| `WPNAV_ACCEL_Z` | `WP_ACC_Z` | cm/s²→m/s² |
| `WPNAV_SPEED_UP/DN` | `WP_SPD_UP/DN` | cm/s→m/s |

官方Mission Planner迁移issue在部分ATC角加速度行写了线加速度单位；固定姿态控制源码明确是角加速度。本文据此**标明来源表述不一致**，不把它们悄悄混合成同一种物理量。主文使用的正确物理量是cdeg/s²→deg/s²。[G06](#g06)[G07](#g07)

`PSC_*`尤其不能整组乘同一个比例。迁移资料列出不同字段有不同缩放，不能仅用字符串替换实现可靠升级。本教程工具只提示名称混用，不自动转换任何参数。

### B.5 把PID数值当物理常数的误区

同样的P=0.1，在不同控制器定义、输出归一化、单位、滤波和采样条件下，可能没有可比性。不能从另一台飞机的“最佳P”直接推导自己的值。

主循环频率更高、DShot数字更大、GNSS更新更快都不自动代表闭环更好。还要看噪声、执行器带宽、延迟、资源和数据新鲜度。一个频率必须附带“谁以这个频率在做什么”。

## 附录 C. 一次完整的日志复盘工作坊

本附录假定你已经有真实BIN与飞手事件记录。没有提供实际飞行日志时，以下都是**分析步骤和假设例子**，不是对你们某次故障的诊断。

### C.1 先确认日志身份，不急着画曲线

记录文件哈希、飞机编号、固件、开始时间、电池、载荷、飞手和参数快照。确认BIN是本架次，而不是同一天上一架次；确认tlog来自正确system ID。保存原件，不在原件上截断或改写。

在Mission Planner打开DataFlash日志，查看版本/参数、模式/事件和起止时间。异常发生在起飞前、整定阶段、任务转场还是着陆？如果飞控曾重启，日志可能切成多个文件；用供电与时间证据连接，不把每个文件都视为完整任务。[S27](#s27)[S28](#s28)

### C.2 先做“事件时间线”

建立一个小表，至少标记：解锁、起飞、进入Loiter、调参开始、每轴结束、保存、切模式、载荷动作、定位质量变化、降落、上锁。Lua脚本消息与BIN中的QUIK记录可互相帮助定位，但地面无线文本可能丢失，不能要求每条文字都齐全才相信机载日志。[G02](#g02)

发现飞控模式从GUIDED变为LAND时，先找导致模式变化的原因，再分析轨迹偏离。此后位置目标可能仍被上层发布，但飞控不再按原模式跟随，不能据此说“位置环突然失效”。

### C.3 姿态与角速度配对看

在同一轴和同一时间窗口，将期望与实际叠加。先选几秒到十几秒能看清动作的窗口，再对可疑片段放大。横滚、俯仰和偏航的环绕处理不同，接近±180°的偏航误差应使用最短角差，不直接相减得到358°。

一个合理的评价顺序是：目标是否合理→延迟是否稳定→最大超调→回摆次数→收敛时间→噪声底→电机输出余量。不要在整个十分钟日志上用一条RMS替代具体事件。

“目标看起来抖”要先确认它究竟是任务位置目标、姿态目标还是角速度目标。一个离散位置阶跃经飞控内部整形后可以产生连续姿态目标；相反，20Hz更新也可能携带不连续的位置或速度变化。[S30](#s30)[G06](#g06)

### C.4 输出饱和与重心问题

对照同一时间的各电机输出、总推力估计和电池电压。某一路长期高、对侧长期低，可能对应重心偏移、桨/电机差异或控制需求；不能只看平均油门正常就排除饱和。

单瓶A1和单瓶A2分别测试能揭示非对称性。如果两种状态一侧电机都长期更高，应检查结构、推力差异或固定偏置；若偏差随载荷位置翻转，则重心与机构布局更值得优先研究。这是推理方向，需要实测支持。

记录下降、刹车和偏航时是否出现同时饱和。多旋翼的总推力、roll、pitch和yaw共享执行器能力；不能为追求yaw灵敏把其他轴余量耗尽。[G02](#g02)[G03](#g03)

### C.5 VIBE、Clipping、频谱与陷波

VIBE用于观察振动水平；Clipping计数增加意味着传感器量程边界等问题值得检查。陷波能处理某些频率的噪声，**不能还原已经裁剪丢失的测量**。[S19](#s19)

频谱检查尽量利用适当的原始/批量IMU记录或官方支持的分析链。记录配置会消耗SD带宽与计算资源，先地面确认可写，不为“更全面”无限增加采样与传感器实例。[S54](#s54)[S67](#s67)

有电机RPM时，比较峰值是否随转速移动，再选择RPM跟踪或其他适合来源。固定陷波适合什么、动态陷波适合什么由噪声证据决定。设置后要查看滤波是否覆盖实际峰值，以及姿态响应是否因为额外延迟恶化。

### C.6 EKF、GPS与RTK分层看

同时看GPS解类型、精度估计、卫星/几何、EKF相关状态与创新检验、模式事件、本地位置和速度。GNSS定位突然跳，而EKF拒绝该数据，与EKF接受跳变后local发生变化，是不同情况。[S49](#s49)

创新通常指观测与预测的不一致；大创新可能来自观测错误，也可能来自模型、时延或其他状态错误。不能只因为某个创新大，就把对应噪声参数调大让它“看起来通过”。

固定解丢失后先看修正龄期与链路计数；若修正一直正常，再考虑遮挡、共同观测、多路径、接收机角色与天线问题。若所有传感器同时短暂消失，优先寻找电源/重启/通信拥塞证据。

### C.7 AutoTune与QuickTune日志怎样看

内置AutoTune重点将整定阶段、测试目标、实际响应和最终保存对应起来；不同版本日志字段需要读当前格式。Lua QuickTune的`QUIK`记录包含脚本写入的`SRate,Gain,Param`，可观察当前轴、阶段和增益变化。[G02](#g02)[G03](#g03)

按该固定Lua算法，理想无中断增长在半对数坐标上近似直线；出现平台可能是飞手输入等待、阶段延迟、已完成或其他条件，不应立即判定“脚本挂了”。检测到边界后应有回退过程，最终持久值还要通过参数快照验证。

### C.8 如何写一条合格结论

不合格：“调了以后好多了，应该没问题。”

合格格式：“F012与F014使用同机、同类电池和同一载荷；本次仅改变经过审阅的滤波/整定候选。选取相似动作窗口后，期望—实际跟踪、输出峰值、收敛时间和电机温度的比较见表。还未验证低电量与单瓶A2，因此仅放行下一阶段，不放行全任务。”

日志统计最好保留窗口和处理参数。不同人选不同时间段、不同滤波和不同坐标定义，可能得到看似矛盾但并不互相否定的结果。

## 附录 D. 必须掌握的数学与工程估算

以下都是明确假设下的教学模型，不是无需实飞验证的性能保证。

### D.1 静态偏差、动态误差和测量噪声

静态偏差像一把整体错了刻度的尺；噪声像每次读数随机抖；动态误差像读到了过去的位置。分别对应标定、滤波与时间/系统带宽问题。把噪声滤平不会自动消除偏差；把P调大不会自动消除测量延迟。

若飞机水平速度为v、图像对应位姿延迟误差为Δt，则一阶位置误差约为`v·Δt`。在12m/s时，50ms对应0.6m；这不是说你们当前误差一定为0.6m，而是说明高速下时间问题不能忽略。

### D.2 阶跃响应四个词

**上升时间**描述从起点接近期望值的速度；**超调**描述越过目标多少；**整定时间**描述回到某误差带并保持的时间；**稳态误差**描述长期偏差。必须说明误差带和观察窗口，否则整定时间没有统一含义。

对任务投放，可能宁可慢0.3秒，也要减少来回穿越目标与图像抖动；对长距离转场，则更关注推力、加减速和航线余量。最优“手感”不等于最优任务表现。

### D.3 EMA、中值与滤波延迟

EMA可写成`y[k]=(1−α)y[k−1]+αx[k]`。α越小一般越平滑，但响应更慢。中值能抑制少数离群值，却不是消除所有错误的万能工具。若时间不一致或坐标原点错了，再复杂滤波也只是在平滑错误数据。

在频域看滤波时还应考虑相位。截止频率降低可能减少高频噪声，也可能使闭环可用带宽降低。QuickTune所需的干净测量与快速响应要共同取得平衡，而非“滤波越多越好”。[S53](#s53)

### D.4 RPM、电角转速与频率

机械转速N rpm的转频为`N/60` Hz。若某源输出电角转速，换算还与电机极对数有关。对一个有14个磁极、7极对的假设电机，电角转速与机械转速相差7倍；14是磁极数，不是極对数。

桨叶通过频率、轴转频、结构谐振及其谐波可能不同。频谱有一个峰不能直接说它就是电机转频。ESC遥测源与陷波解释必须核对量纲与极数配置。[S16](#s16)[S55](#s55)

### D.5 理想制动距离

恒定水平减速度a、忽略jerk和风：

\[
d_{brake}=\frac{v_0^2-v_1^2}{2a}
\]

如果还存在反应/通信/执行延迟τ，延迟期间近似保持v₀，则再加`v₀τ`。工程上还必须留定位误差、扰动与边界裕度。

取a=3m/s²，仅作为例子：

| 初速→末速 | 理想制动距离 | 若额外延迟0.2s |
|---|---:|---:|
| 4→0m/s | 2.67m | 3.47m |
| 6→0m/s | 6.00m | 7.20m |
| 8→0m/s | 10.67m | 12.27m |
| 12→0m/s | 24.00m | 26.40m |
| 12→6m/s | 18.00m | 20.40m |

因此，在侦察区前仅预留1.5m减速，不能在这个假设下把12m/s降到6m/s。应先改变轨迹设计，而非只提高飞控参数。

### D.6 距离短时根本到不了设定最高速度

起点终点都静止，加减速度大小均为a，速度上限v。达到v再降回0至少需要距离`v²/a`。

距离L较短时是三角速度：`v_peak=√(aL)`，`T=2√(L/a)`；较长时才有匀速段，`T=L/v+v/a`。这个模型没有jerk约束和飞控跟踪延迟，仍然只是理想参考。

L=30m、a=3m/s²、v上限12m/s，实际理想峰速约9.49m/s，静止到静止约6.32s。把30m直接除12得到2.5s，忽略了起停条件。

### D.7 v11的梯形时间规划隐含多大加速度

当最小段时间未主导时，v11有`T=L/(0.8v)`，加速段占0.2T，因此隐含`a=v/(0.2T)=4v²/L`。[P1](#p1)

对L=30m、v=12m/s，隐含a=19.2m/s²。理想定高且无阻力时，水平加速度与倾角关系是`a≈g·tanθ`，对应约63°。这说明**设置点曲线可以算出来，并不说明实际满载飞机可以跟上**。

### D.8 倾角、推力和风中的投放

定高时总推力约为`mg/cosθ`。30°需要约1.155倍重力的推力；60°需要约2倍。飞机还要留出动态、偏航与扰动控制余量。这里不包含空气阻力和其他损失。

持续侧风下，为保持位置飞机可能需要固定倾角。若这个平衡倾角超过状态机投放门限，即使控制无振荡也不能通过。应分析风和门限适用性，不让PID承担“让飞机无倾角抵抗水平风”的不可能任务。

### D.9 投掉水瓶为什么会抬头或上冲

质量下降、重心变化和转动惯量变化是三个不同效应。若释放瞬间推力来不及变化，原推力对应的`T/m`增大，可能上冲；若瓶子在侧面，原先平衡重心的力矩需求也改变。机构反作用、摆动、气压扰动又可能叠加。

无法仅由水瓶体积精确算出整机动态，因为还缺空机质量、安装位置、控制器和释放时间。把双瓶→A1单瓶、双瓶→A2单瓶分开测试，比只测试空载更有信息。

### D.10 航向误差如何变成远处横向误差

若实际场地轴与锁定的轴相差δ，沿前方L规划的点可出现约`L·sinδ`横向偏移。L=60m，δ=1°时约1.05m；δ=2°时约2.09m。

RTK厘米级定位不能自动修复错误的场地航向。这就是为什么“飞机位置准”与“路线在场地内”需要不同验收。[P1](#p1)

### D.11 Fixed时间占比与真值精度

均匀采样且不丢数据时，样本占比可以近似时间占比；若丢包很不均匀，必须按时间段统计。两个相邻样本之间很长的空洞不能无条件沿用前一个Fixed状态。

有固定解率、hAcc统计、静态散布仍不足以证明绝对误差。要验证绝对位置，需要独立且同参考系的真值；要验证投放，需要实际水瓶第一落点。不同层的“通过”不能互相替代。

## 附录 E. 完整离线实践源码

以下6个Python文件与配套ZIP内容一致。采用Python 3.10+语法，实际测试环境为3.13.5；只用标准库，不需要pip安装。将它们按路径放在同一个`tools`目录。共享的`csv_common.py`不能遗漏。

它们没有串口、网络或飞控写入接口。不产生可直接导入飞控的整机参数。数学演示不是实际QuickTune或飞行器仿真；连续性统计不是原v11安全逻辑的逐行替代。

### E.1 `tools/param_audit.py`

学习严格输入校验、非有限数、重复项、字典、位掩码和差异。只输出人工审阅提示，不能证明配置安全。

```python
#!/usr/bin/env python3
"""离线读取/比较参数快照；从不连接飞控、不写参数、不产生可导入配置。"""
from __future__ import annotations
import argparse
import math
import re
from pathlib import Path
from typing import Mapping

NAME = re.compile(r"^[A-Z][A-Z0-9_]{0,63}$")

def parse_params(text: str) -> dict[str, float]:
    """支持 NAME,VALUE、NAME VALUE 与 QGC 的 SYS COMP NAME VALUE TYPE。"""
    result: dict[str, float] = {}
    for line_no, raw in enumerate(text.splitlines(), 1):
        line = re.split(r"#|;|//", raw, maxsplit=1)[0].strip()
        if not line:
            continue
        fields = [v.strip() for v in line.split(",")] if "," in line else line.split()
        if len(fields) == 2:
            name, value_text = fields
        elif len(fields) == 5:
            try:
                int(fields[0]); int(fields[1]); int(fields[4])
            except ValueError as exc:
                raise ValueError(f"第{line_no}行：不是受支持的QGC五列格式") from exc
            name, value_text = fields[2], fields[3]
        else:
            raise ValueError(f"第{line_no}行：需要2列或QGC 5列，实际{len(fields)}列")
        if not NAME.fullmatch(name):
            raise ValueError(f"第{line_no}行：无效参数名 {name!r}")
        if name in result:
            raise ValueError(f"第{line_no}行：重复参数 {name}，拒绝静默覆盖")
        try:
            value = float(value_text)
        except ValueError as exc:
            raise ValueError(f"第{line_no}行：{name}不是数值") from exc
        if not math.isfinite(value):
            raise ValueError(f"第{line_no}行：{name}非有限值")
        result[name] = value
    if not result:
        raise ValueError("参数文件没有有效参数")
    return result

def int_field(name: str, value: float) -> int:
    if not math.isfinite(value) or not float(value).is_integer() or value < 0:
        raise ValueError(f"{name}应为非负整数，实际{value}")
    return int(value)

def audit(params: Mapping[str, float], family: str | None = None) -> list[str]:
    notes: list[str] = []
    if "ARMING_CHECK" in params:
        value = int_field("ARMING_CHECK", params["ARMING_CHECK"])
        if value & 1 == 0:
            notes.append("旧版ARMING_CHECK未选择All位：核查被省略的检查，不能自动判为安全")
    if "ARMING_SKIPCHK" in params:
        value = int_field("ARMING_SKIPCHK", params["ARMING_SKIPCHK"])
        if value != 0:
            notes.append("新版ARMING_SKIPCHK非0：存在跳过检查的位，逐项审阅")
    if "ARMING_CHECK" in params and "ARMING_SKIPCHK" in params:
        notes.append("同时出现新旧解锁检查名称：核查快照来源/版本，禁止按数值互换")
    if not any(p in params for p in ("ARMING_CHECK", "ARMING_SKIPCHK")):
        notes.append("快照缺解锁检查字段：这是信息不足，不是检查已通过")
    for index in (9, 10):
        key = f"SERVO{index}_FUNCTION"
        if key not in params:
            notes.append(f"缺少{key}：无法确认v11投放输出用途")
        elif params[key] != 0:
            notes.append(f"{key}={params[key]:g}：必须核对输出用途及DO_SET_SERVO兼容性，不自动修改")
    bindings: dict[int, list[str]] = {}
    for name, value in params.items():
        if re.fullmatch(r"RC\d+_OPTION", name):
            func = int_field(name, value)
            if func:
                bindings.setdefault(func, []).append(name)
    for func, names in bindings.items():
        if len(names) > 1:
            notes.append(f"辅助功能{func}重复绑定{', '.join(sorted(names))}：核查是否有意及是否冲突")
    if params.get("QUIK_ENABLE", 0) > 0 and params.get("QWIK_ENABLE", 0) > 0:
        notes.append("QUIK与QWIK同时使能：检查是否误启两种调参器；快照不能证明实际脚本已加载")
    if params.get("QUIK_ENABLE", 0) > 0:
        notes.append("QUIK处于使能状态：比赛前核对脚本/RC；固定Lua中ENABLE=0不等于空中回退")
    if family == "4.7" and any(k in params for k in ("WPNAV_SPEED", "ANGLE_MAX", "LAND_SPEED")):
        notes.append("声明4.7但含旧导航/角度参数名：核对实际固件及迁移，不自动换算")
    if family in ("4.5", "4.6") and any(k in params for k in ("WP_SPD", "ATC_ANGLE_MAX", "LAND_SPD_MS")):
        notes.append("声明旧版本但含4.7名称：核查快照，不把新单位填进旧参数")
    if family is None:
        notes.append("未指定固件系列：不推断单位；名称不是可靠的完整固件版本证据")
    return notes

def differences(before: Mapping[str, float], after: Mapping[str, float]) -> list[str]:
    out: list[str] = []
    for name in sorted(set(before) | set(after)):
        if name not in before:
            out.append(f"ADDED   {name}: {after[name]:.9g}")
        elif name not in after:
            out.append(f"REMOVED {name}: {before[name]:.9g}")
        elif before[name] != after[name]:
            out.append(f"CHANGED {name}: {before[name]:.9g} -> {after[name]:.9g}")
    return out

def main() -> None:
    parser = argparse.ArgumentParser(description=__doc__)
    parser.add_argument("snapshot", type=Path)
    parser.add_argument("--compare", type=Path)
    parser.add_argument("--family", choices=("4.5", "4.6", "4.7"))
    args = parser.parse_args()
    try:
        before = parse_params(args.snapshot.read_text(encoding="utf-8-sig"))
        print("只读审阅；没有警告不代表可安全飞行；不自动修改任何配置。")
        print(f"快照参数数：{len(before)}")
        for note in audit(before, args.family):
            print("CHECK:", note)
        if args.compare:
            after = parse_params(args.compare.read_text(encoding="utf-8-sig"))
            print("\n参数差异（精确数值比较）：")
            print("\n".join(differences(before, after)) or "无数值差异")
            print("\n后快照审阅：")
            for note in audit(after, args.family):
                print("CHECK:", note)
    except (OSError, UnicodeError, ValueError) as exc:
        parser.exit(2, f"输入错误：{exc}\n")

if __name__ == "__main__":
    main()
```

### E.2 `tools/braking_budget.py`

学习速度/加速度量纲、制动与静止起停模型，并计算v11时间分配隐含的加速度。

```python
#!/usr/bin/env python3
"""离线理想制动/轨迹算例；不是实机可飞性验证或飞行参数生成器。"""
from __future__ import annotations
import argparse
import math

def finite(value: float, name: str, positive: bool = False) -> float:
    if not math.isfinite(value) or value < 0 or (positive and value == 0):
        raise ValueError(f"{name}必须为有限{'正' if positive else '非负'}数")
    return value

def stopping_distance(speed: float, accel: float, latency: float = 0.0,
                      end_speed: float = 0.0) -> float:
    for value, name in ((speed, "speed"), (latency, "latency"), (end_speed, "end_speed")):
        finite(value, name)
    finite(accel, "accel", True)
    if end_speed > speed:
        raise ValueError("末速度大于初速度，不是制动过程")
    return speed * latency + (speed * speed - end_speed * end_speed) / (2.0 * accel)

def rest_to_rest(distance: float, speed_limit: float, accel: float) -> tuple[float, float]:
    finite(distance, "distance")
    finite(speed_limit, "speed_limit", True)
    finite(accel, "accel", True)
    if distance <= speed_limit * speed_limit / accel:
        peak = math.sqrt(distance * accel)
        return 2.0 * peak / accel, peak
    return distance / speed_limit + speed_limit / accel, speed_limit

def v11_profile(distance: float, speed_limit: float, min_time: float = 1.0) -> tuple[float, float, float]:
    """按v11时间分配推导：返回时长、真实setpoint峰速、隐含加速度。"""
    finite(distance, "distance")
    finite(speed_limit, "speed_limit", True)
    finite(min_time, "min_time", True)
    duration = max(min_time, distance / (0.8 * speed_limit))
    peak = distance / (0.8 * duration)
    return duration, peak, peak / (0.2 * duration)

def main() -> None:
    parser = argparse.ArgumentParser(description=__doc__)
    parser.add_argument("--distance", type=float, required=True)
    parser.add_argument("--speed", type=float, required=True)
    parser.add_argument("--accel", type=float, required=True)
    parser.add_argument("--latency", type=float, default=0.0)
    parser.add_argument("--end-speed", type=float, default=0.0)
    args = parser.parse_args()
    try:
        d = stopping_distance(args.speed, args.accel, args.latency, args.end_speed)
        duration, peak = rest_to_rest(args.distance, args.speed, args.accel)
        old_t, old_v, old_a = v11_profile(args.distance, args.speed)
        angle = math.degrees(math.atan2(old_a, 9.81))
    except ValueError as exc:
        parser.error(str(exc))
    print("数学算例：未计风、jerk、推力余量、空间裕度和实机跟踪误差。")
    print(f"减至{args.end_speed:g}m/s的距离（含指定延迟，不含额外裕度）：{d:.3f}m")
    print(f"理想加速度受限静止→静止：{duration:.3f}s，峰速{peak:.3f}m/s")
    print(f"原v11参考点轨迹：{old_t:.3f}s，峰速{old_v:.3f}m/s，隐含a={old_a:.3f}m/s²")
    print(f"该隐含a的理想定高倾角：{angle:.2f}deg；不代表飞机能达到")

if __name__ == "__main__":
    main()
```

### E.3 `tools/csv_common.py`

两种CSV分析的公共输入层。先拒绝错误结构和时间，再计算统计，避免把坏数据平均成好结果。

```python
"""只读、严格的统一教学CSV解析，不猜测BIN原始字段。"""
from __future__ import annotations
import csv
import math
from pathlib import Path
from typing import Iterable

def read_numeric_csv(path: Path, columns: Iterable[str]) -> list[dict[str, float]]:
    required = set(columns)
    rows: list[dict[str, float]] = []
    with path.open(encoding="utf-8-sig", newline="") as stream:
        reader = csv.DictReader(stream)
        if reader.fieldnames is None:
            raise ValueError("CSV没有表头")
        if len(reader.fieldnames) != len(set(reader.fieldnames)):
            raise ValueError("CSV有重复列名")
        if not required.issubset(reader.fieldnames):
            raise ValueError(f"CSV缺少列：{sorted(required - set(reader.fieldnames))}")
        for number, raw in enumerate(reader, 2):
            if None in raw:
                raise ValueError(f"CSV第{number}行：列数过多")
            parsed: dict[str, float] = {}
            for key in required:
                try:
                    value = float(raw[key])
                except (TypeError, ValueError) as exc:
                    raise ValueError(f"CSV第{number}行：{key}缺失或非数值") from exc
                if not math.isfinite(value):
                    raise ValueError(f"CSV第{number}行：{key}非有限值")
                parsed[key] = value
            if parsed.get("time_s", 0.0) < 0:
                raise ValueError(f"CSV第{number}行：时间不能为负")
            if rows and "time_s" in parsed and parsed["time_s"] <= rows[-1]["time_s"]:
                raise ValueError(f"CSV第{number}行：时间必须严格递增，不接受重复/倒退")
            rows.append(parsed)
    if len(rows) < 2:
        raise ValueError("至少需要两个样本，不能从一个点证明连续性")
    return rows
```

### E.4 `tools/flight_metrics.py`

按统一教学列统计连续好样本跨度。离散观测之间不能证明持续满足，长间隔重置；max_gap不是v11原始参数。

```python
#!/usr/bin/env python3
"""统一CSV中的投放条件离线统计；不能作为飞行/投放放行器。"""
from __future__ import annotations
import argparse
import json
import math
from dataclasses import dataclass
from pathlib import Path
from csv_common import read_numeric_csv

COLUMNS = (
    "time_s", "identity_ok", "area_ok", "center_err_m", "outlet_err_m",
    "predicted_err_m", "height_err_m", "hspeed_mps", "vz_mps",
    "roll_deg", "pitch_deg", "omega_dps",
)

@dataclass(frozen=True)
class Limits:
    center: float = 0.35
    outlet: float = 0.20
    height: float = 0.15
    hspeed: float = 0.15
    vz: float = 0.10
    angle: float = 8.0
    omega: float = 10.0
    stable_s: float = 0.50
    max_gap_s: float = 0.15  # 教学连续性阈值，不是原v11的全局odom超时

def row_valid(row: dict[str, float], limits: Limits) -> bool:
    for name in ("identity_ok", "area_ok"):
        if row[name] not in (0.0, 1.0):
            raise ValueError(f"{name}只能用0/1，不猜测其他状态")
    for name in ("center_err_m", "outlet_err_m", "predicted_err_m", "height_err_m", "hspeed_mps", "omega_dps"):
        if row[name] < 0:
            raise ValueError(f"{name}不能为负；先确认单位和导出方法")
    return (
        row["identity_ok"] == 1 and row["area_ok"] == 1
        and row["center_err_m"] <= limits.center
        and row["outlet_err_m"] <= limits.outlet
        and row["predicted_err_m"] <= limits.outlet
        and row["height_err_m"] <= limits.height
        and row["hspeed_mps"] <= limits.hspeed
        and abs(row["vz_mps"]) <= limits.vz
        and abs(row["roll_deg"]) <= limits.angle
        and abs(row["pitch_deg"]) <= limits.angle
        and row["omega_dps"] <= limits.omega
    )

def evaluate(rows: list[dict[str, float]], limits: Limits = Limits()) -> dict[str, float | int | bool]:
    if len(rows) < 2:
        raise ValueError("至少需要两个样本")
    if any(not math.isfinite(v) or v <= 0 for v in vars(limits).values()):
        raise ValueError("所有教学阈值必须是有限正数")
    start: float | None = None
    previous_t: float | None = None
    previous_good = False
    longest = 0.0
    good_count = 0
    gap_count = 0
    for row in rows:
        if any(key not in row or not math.isfinite(row[key]) for key in COLUMNS):
            raise ValueError("行中存在缺失或非有限字段")
        t = row["time_s"]
        if t < 0 or (previous_t is not None and t <= previous_t):
            raise ValueError("time_s必须非负且严格递增")
        dt = None if previous_t is None else t - previous_t
        large_gap = dt is not None and dt > limits.max_gap_s
        if large_gap:
            gap_count += 1
        good = row_valid(row, limits)
        if good:
            good_count += 1
            if start is None or not previous_good or large_gap:
                start = t
            longest = max(longest, t - start)
        else:
            start = None
        previous_t, previous_good = t, good
    return {
        "samples": len(rows), "good_samples": good_count,
        "large_gaps": gap_count, "longest_observed_good_span_s": longest,
        "meets_demo_dwell": longest + 1e-12 >= limits.stable_s,
    }

def main() -> None:
    parser = argparse.ArgumentParser(description=__doc__)
    parser.add_argument("csv", type=Path)
    parser.add_argument("--max-gap", type=float, default=0.15)
    args = parser.parse_args()
    try:
        result = evaluate(read_numeric_csv(args.csv, COLUMNS), Limits(max_gap_s=args.max_gap))
    except (OSError, UnicodeError, ValueError) as exc:
        parser.exit(2, f"输入错误：{exc}\n")
    print("仅输入CSV的教学统计；离散样本不证明采样间行为，也不证明物理释放。")
    print(json.dumps(result, ensure_ascii=False, indent=2))

if __name__ == "__main__":
    main()
```

### E.5 `tools/rtk_metrics.py`

区分整个观测窗口、可覆盖区间、数据空洞与两端满足Fixed/龄期条件的区间。不是绝对精度评估。

```python
#!/usr/bin/env python3
"""只读RTK CSV统计；Fixed和hAcc不是独立真值精度证明。"""
from __future__ import annotations
import argparse
import json
import math
from pathlib import Path
from csv_common import read_numeric_csv

COLUMNS = ("time_s", "fix_type", "rtcm_age_s", "hacc_m")

def evaluate(rows: list[dict[str, float]], max_gap_s: float = 2.0,
             max_age_s: float = 2.0, max_hacc_m: float = 0.10) -> dict[str, float | int]:
    if len(rows) < 2:
        raise ValueError("至少需要两个样本")
    if any(not math.isfinite(v) or v <= 0 for v in (max_gap_s, max_age_s, max_hacc_m)):
        raise ValueError("阈值必须为有限正数")
    for index, row in enumerate(rows):
        if any(key not in row or not math.isfinite(row[key]) for key in COLUMNS):
            raise ValueError("缺少字段或存在非有限数据")
        if row["time_s"] < 0 or row["rtcm_age_s"] < 0 or row["hacc_m"] <= 0:
            raise ValueError("时间/龄期须非负，hAcc须正值；未知值不能填0伪装精确")
        if row["fix_type"] < 0 or not float(row["fix_type"]).is_integer():
            raise ValueError("fix_type须非负整数，常见MAVLink RTK Fixed为6")
        if index and row["time_s"] <= rows[index - 1]["time_s"]:
            raise ValueError("time_s必须严格递增")
    span = rows[-1]["time_s"] - rows[0]["time_s"]
    covered = fixed = qualified = 0.0
    gaps = 0
    for before, after in zip(rows, rows[1:]):
        dt = after["time_s"] - before["time_s"]
        if dt > max_gap_s:
            gaps += 1
            continue
        covered += dt
        if before["fix_type"] == after["fix_type"] == 6:
            fixed += dt
            if (before["rtcm_age_s"] <= max_age_s and after["rtcm_age_s"] <= max_age_s
                and before["hacc_m"] <= max_hacc_m and after["hacc_m"] <= max_hacc_m):
                qualified += dt
    return {
        "samples": len(rows), "window_s": span, "covered_intervals_s": covered,
        "uncovered_s": max(0.0, span - covered), "large_gaps": gaps,
        "both_endpoints_fixed_s": fixed,
        "both_endpoints_qualified_s": qualified,
        "fixed_intervals_over_whole_window_pct": 100.0 * fixed / span,
        "qualified_intervals_over_whole_window_pct": 100.0 * qualified / span,
    }

def main() -> None:
    parser = argparse.ArgumentParser(description=__doc__)
    parser.add_argument("csv", type=Path)
    parser.add_argument("--max-gap", type=float, default=2.0)
    parser.add_argument("--max-age", type=float, default=2.0)
    parser.add_argument("--max-hacc", type=float, default=0.10)
    args = parser.parse_args()
    try:
        result = evaluate(read_numeric_csv(args.csv, COLUMNS), args.max_gap, args.max_age, args.max_hacc)
    except (OSError, UnicodeError, ValueError) as exc:
        parser.exit(2, f"输入错误：{exc}\n")
    print("教学阈值，不是ArduPilot默认准入标准；只计短间隔两端都满足的区间。")
    print(json.dumps(result, ensure_ascii=False, indent=2))

if __name__ == "__main__":
    main()
```

### E.6 `tools/quicktune_math.py`

只计算指数增益增长和振荡分支的简化回退限制；没有执行整定，没有模拟真实振荡，也不处理全部源码分支。

```python
#!/usr/bin/env python3
"""简化单参数QuickTune数学练习，无Lua上传、无飞控连接、无写参数。"""
from __future__ import annotations
import argparse
import math

def multiplier(rate_hz: float = 40.0, double_time_s: float = 10.0) -> float:
    if any(not math.isfinite(v) or v <= 0 for v in (rate_hz, double_time_s)):
        raise ValueError("频率与翻倍时间必须是有限正数")
    exponent = math.log(2.0) / rate_hz / double_time_s
    if exponent > 700:
        raise ValueError("输入导致不合理的指数溢出")
    return math.exp(exponent)

def backed_off(initial: float, detected: float, gain_margin: float = 60.0,
               max_reduce: float = 20.0) -> tuple[float, float, float]:
    if not math.isfinite(initial) or initial <= 0:
        raise ValueError("初值须有限且大于0")
    if not math.isfinite(detected) or detected < 0:
        raise ValueError("检测值须有限且非负")
    if any(not math.isfinite(v) or not 0 <= v <= 100 for v in (gain_margin, max_reduce)):
        raise ValueError("比例必须在0至100之间")
    raw = detected * (1.0 - gain_margin / 100.0)
    floor = initial * (1.0 - max_reduce / 100.0)
    return raw, floor, max(raw, floor)

def main() -> None:
    parser = argparse.ArgumentParser(description=__doc__)
    parser.add_argument("--initial", type=float, required=True)
    parser.add_argument("--detected", type=float, required=True)
    parser.add_argument("--margin", type=float, default=60.0)
    parser.add_argument("--max-reduce", type=float, default=20.0)
    parser.add_argument("--double-time", type=float, default=10.0)
    args = parser.parse_args()
    try:
        m = multiplier(40.0, args.double_time)
        raw, floor, final = backed_off(args.initial, args.detected, args.margin, args.max_reduce)
    except ValueError as exc:
        parser.error(str(exc))
    print("仅演示振荡分支的简化数学；未模拟yaw上限、联动P/I、保护与实际振荡。")
    print(f"40Hz名义每步倍率={m:.9f}")
    print(f"回退计划={raw:.6f}，初始基线下限={floor:.6f}，受限结果={final:.6f}")

if __name__ == "__main__":
    main()
```

### E.7 Lua练习的位置

完整只读Lua文件已在第49章列出，ZIP中路径为`lua/bench_readonly_status.lua`。官方会实际修改参数的QuickTune未在本工程复制或改写，请通过[G02](#g02)阅读固定源码并按第45～50章核对。

### E.8 合成CSV与预期结果

`examples/flight.csv`含81个合成样本；默认练习统计得到56个合格样本，最长可观测合格跨度1.75秒。它不代表任何一次真机飞行。

`examples/rtk.csv`覆盖30秒窗口，其中5秒是无法由允许间隔覆盖的数据空洞；两个端点均Fixed的短区间合计20秒，满足示例龄期/hAcc条件的区间合计18秒。因此占整个窗口的比例分别约66.67%和60%。不同统计定义会有不同值，报告必须写明定义。

合成参数`before.param`和`after.param`含刻意安排的变化与风险提示。它们仅用于验证解析器，禁止导入飞控。

## 附录 F. 十份可复制的团队记录模板

ZIP的`templates`目录已经提供独立文件。空白表示待测或待核对，不等于默认通过。下列四反引号围栏内就是各Markdown文件原文，可复制后按实际架次填写。

### F.1 `01_整机身份与版本.md`

````markdown
# 整机身份与版本记录

状态：未填写，不能作为放行记录。

| 字段 | 实际填写 |
|---|---|
| 机体唯一编号 | |
| CUAV型号/硬件修订/载板 | |
| 飞控序列号与固件目标 | |
| ArduCopter版本/构建标识 | |
| 固件来源与固定链接 | |
| Mission Planner版本 | |
| 电机/桨/ESC型号及固件 | |
| ESC协议与输出分组 | |
| 电池规格/电源模块/BEC | |
| 空载、A1、A2、双瓶总质量 | |
| GNSS/RTK型号、固件、天线 | |
| 遥控器/接收机/协议 | |
| 数传型号、固件、配置工具 | |
| O4版本、供电与安装方向 | |
| NUC系统/ROS/MAVROS版本 | |
| 状态机版本、工作空间提交 | |
| 视觉模型/标定/参数版本 | |
| Lua脚本固定提交与本地SHA256 | |
| 原始全参数文件及SHA256 | |
| 审阅人、日期、待解决项 | |

“同型号”不等于同校准、同输出或同参数。共享文件前删除密码、无线密钥和非公开位置。
````

### F.2 `02_供电接线与输出.md`

````markdown
# 供电、串口、总线与输出表

## 供电

| 支路 | 输入/输出电压 | 连续/峰值能力 | 负载 | 保险/保护 | 地线/回流路径 | 实测压降 |
|---|---|---|---|---|---|---|
| 飞控 | | | | | | |
| 舵机 | | | | | | |
| NUC | | | | | | |
| O4 | | | | | | |
| 数传/GNSS | | | | | | |

## 通信

| 实物接口 | SERIAL/CAN驱动实例 | 协议 | UART/总线速率 | 对端型号 | 线束针脚依据 | 配置保存位置 |
|---|---|---|---|---|---|---|
| | | | | | | |

## 输出

| 实物插口 | SERVO逻辑号 | FUNCTION | 电机测试字母/物理位置 | PWM/DShot及分组 | 供电 | 无桨验证 |
|---|---|---|---|---|---|---|
| | | | | | | |

## 投放机构

| 项目 | A1 | A2 |
|---|---|---|
| 实际输出与固件功能 | | |
| 空载行程/受力行程 | | |
| 待机/释放PWM | | |
| 指令至真实脱离延迟 | | |
| 保持时间与回位 | | |
| 供电峰值/卡滞保护 | | |
| 位置外参及参考点 | | |
| 机械反馈/观察证据 | | |

检查前拆桨、支撑载荷；ACK只能证明命令层的一部分，不是释放传感器。
````

### F.3 `03_RC与模式开关.md`

````markdown
# RC、模式与辅助开关核对表

| 通道 | 发射机控制件 | 飞控读到的低/中/高 | 功能原名和枚举 | 正常飞行位置 | 失联行为 | 冲突检查 |
|---|---|---|---|---|---|---|
| Roll | | | | | | |
| Pitch | | | | | | |
| Throttle | | | | | | |
| Yaw | | | | | | |
| Flight mode | | | | | | |
| 调参专用 | | | | | | |
| 应急功能 | | | | | | |

模式已验证情况：

| 模式 | 依赖定位/高度源 | 进入前条件 | 正常用途 | 定位失效时是否仍可用 | 验证证据 |
|---|---|---|---|---|---|
| Stabilize | | | | | |
| AltHold | | | | | |
| Loiter | | | | | |
| GUIDED | | | | | |
| LAND/RTL | | | | | |

确认开关逻辑，不以开关外观方向代替LOW/MID/HIGH。紧急断动力与切换可控模式不是同一动作。
````

### F.4 `04_基站与RTK验收.md`

````markdown
# RTK基站卡与端到端验收

## 基站身份

| 字段 | 填写 |
|---|---|
| 站点代号、实际固定点 | |
| 接收机/固件/天线型号 | |
| Survey-in或固定坐标模式 | |
| 坐标来源、参考系、历元 | |
| 纬度、经度、高度定义 | |
| 天线参考面与天线高 | |
| 本次是否挪动天线 | |
| RTCM格式、消息类型与率 | |
| 注入路径/数传链路 | |
| NTRIP服务信息（不记密码） | |
| 机载接收机角色/输入接口 | |

## 试验

| 场景 | 持续时间 | 可观测比例 | Fixed时间比例 | 修正龄期 | hAcc/vAcc | 散布/真值误差定义 | 结论 |
|---|---|---|---|---|---|---|---|
| 开阔地静态 | | | | | | | |
| 同点重启 | | | | | | | |
| O4与数传开启 | | | | | | | |
| 舵机动作 | | | | | | | |
| 地面中断修正与恢复 | | | | | | | |

没有独立真值时写“散布/重复性”，不写“绝对定位精度”。试验保持无桨或飞机不飞；不在空中临时换基站。
````

### F.5 `05_调参架次记录.md`

````markdown
# 调参架次实验单

| 字段 | 填写 |
|---|---|
| 架次ID/机体ID/日期/地点代号 | |
| 飞手/观察员/记录员 | |
| 风、温度、地面、能见条件 | |
| 电池ID/电量/内阻或健康记录 | |
| 空载/A1/A2/双瓶及质量 | |
| 飞前参数/固件/滤波/脚本版本 | |
| 本次唯一假设 | |
| 本次变更项目 | |
| 已知风险与中止动作 | |
| 预期指标/观察窗口/阈值 | |
| 实际模式与调参器 | |
| 开始、完成、保存时间 | |
| BIN/tlog/视频/地面消息 | |
| 飞后电机/ESC/供电温度 | |
| 新增故障/饱和/定位异常 | |
| 参数重启读回是否一致 | |
| 接受、拒绝或待定 | |
| 已验证包络和禁止扩展项 | |
| 审阅人签名/下一步 | |

对比实验说明：同一目标动作、相近环境、相同载荷配置；无法控制的变量也要记录。
````

### F.6 `06_失效保护矩阵.md`

````markdown
# 失效保护联合验证矩阵

先在隔离仿真/无桨台架测试可验证部分；任何带桨故障试验需独立风险评审。

| 失效 | 谁检测 | 检测阈值与来源 | 飞控动作 | 上位机动作 | 最后飞手动作 | 会否冲突 | 证据/状态 |
|---|---|---|---|---|---|---|---|
| RC失联 | | | | | | | |
| 地面MAVLink失联 | | | | | | | |
| NUC进程退出但MAVROS存活 | | | | | | | |
| NUC整机断电 | | | | | | | |
| 位置setpoint停止 | | | | | | | |
| RTK修正停止 | | | | | | | |
| GNSS失效/位置跳变 | | | | | | | |
| 视觉断流/时间无法对齐 | | | | | | | |
| 舵机ACK丢失/机构卡滞 | | | | | | | |
| 电池低/临界电量 | | | | | | | |
| 越界或姿态异常 | | | | | | | |
| 调参脚本异常 | | | | | | | |

检测一个进程的存在，不等于它仍在产生新鲜、正确的控制目标。安全逻辑需要端到端验证。
````

### F.7 `07_故障复盘单.md`

````markdown
# 故障复盘单

## 原始事实

事件ID：
机体/固件/参数/载荷：
最后一次已知正常操作：
最早出现的异常（时间与完整文本）：
飞手观察（与推断分开）：
原始日志和录像：
是否发生重启/模式切换/供电异常：

## 假设与验证

| 假设 | 支持证据 | 反对证据 | 下一项低风险验证 | 结果 |
|---|---|---|---|---|
| | | | | |

## 修改与回归

根因是否确定：
实际修改：
回滚文件：
回归测试：
仍未解释的问题：
哪些功能继续禁止使用：
负责人和关闭日期：

不得把“关闭报错检查后能解锁”写成故障已修复。
````

### F.8 `08_载荷与速度包络.md`

````markdown
# 载荷、速度与任务包络验收

| 架次 | 载荷 | 电池 | 目标速度 | 实际峰速 | 实际最大减速度 | 开始制动距离 | 高度偏差 | 横向偏差 | 稳定恢复时间 | 结论 |
|---|---|---|---|---|---|---|---|---|---|---|
| | | | | | | | | | | |

## 每个速度级开始前

已计算制动距离和额外裕度：
试验空域足够且没有人员/障碍：
上一速度级无未解释异常：
不同时首次验证新载荷、新定位源、新PID：
中止与返航路线：
最大允许高度/横向/定位异常：

## 投放阶段

| 配置变化 | 机构真实释放 | 姿态/高度瞬态 | 恢复到稳定门时间 | 有无饱和 | 第一落点证据 |
|---|---|---|---|---|---|
| 双瓶→A1单瓶 | | | | | |
| 双瓶→A2单瓶 | | | | | |
| A1单瓶→空载 | | | | | |
| A2单瓶→空载 | | | | | |

速度数值是试验结果，不是通过提高setpoint参数就自动获得的性能。
````

### F.9 `09_自动调参双流程卡.md`

````markdown
# 自动调参操作卡：先确认是哪一种

## 内置AutoTune（按本文固定源码的普通辅助开关流程）

准备：原参数备份、基本可飞、滤波验证、合格飞手、开阔场、其他调参器关闭。
开始：在支持的稳定飞行条件下启用；观察测试与轴阶段。
调整位置：飞手优先保持安全；按该实现恢复/继续的行为操作。
完成：按对应开关流程试用新结果，不把完成当永久保存。
接受：保持适用的接受/测试状态，受控落地并disarm保存。
拒绝：退出整定恢复原值，安全落地，读回核对。
复核：导出前后差异、重启读回、全载荷验收。

## 官方Lua VTOL-quicktune（固定提交见主教程）

准备：匹配固件API、唯一脚本、正常滤波、QUIK参数、独立三段开关、AUTO_SAVE关闭、原参数备份。
LOW：停止/恢复尚未保存的变化，确认reverted；它与ENABLE=0不是同一语义。
MID：armed且likely_flying条件下整定，默认每轴先D后P。
飞手输入：暂停继续增益增加，输入停止约4秒后继续；不要假设自动恢复原增益。
接受：完成并评价后，在落地前HIGH，看到saved，再受控降落。
拒绝：保存前LOW并确认回退，再受控落地；已经保存的值不能靠LOW恢复成旧备份。
异常：模式切换、ENABLE=0和pcall捕获错误不构成统一的自动回退保证。
复核：导出全参数、重启读回；比赛前地面停用/移走调参脚本，核对加载校验。

以上均为赛前试验，不在正式自主任务中进行。
````

### F.10 `10_比赛冻结与归档.md`

````markdown
# 比赛配置冻结清单

版本冻结日期、负责人：
机体身份与硬件清单：
固件完整版本和来源：
已审阅参数快照：
SD脚本列表及校验：
ROS工作空间/launch/YAML版本：
视觉模型/外参/相机序列号：
RTK基站卡及修正路径：
O4图传配置与判读流程：
数传配置、系统ID和频率协调：
电池、舵机、载荷安装与行程：
所有临时调参入口已停用并验证：
全流程重复验收与原始日志：
异常退出已验证的项目：
当日环境与已验证包络比较：
最近一次变更的回归结果：
回滚包路径及恢复步骤：
第二人复核：

未完成项及禁止飞行/禁止功能：

不能以“上次飞过”替代本次配置和现场条件核对。
````

### F.11 文件指纹怎样记录

Linux可使用`sha256sum 文件名`；Windows PowerShell可使用`Get-FileHash -Algorithm SHA256 -LiteralPath "文件名"`。散列用于确认文件身份，不评价飞控参数是否合适。Lua的Git blob SHA与本地SHA256不是同一种哈希，不能直接比较字符串。

## 附录 G. 30个阶段性练习与参考答案

先独立回答，再看答案。答案不替代实物针脚图、对应固件元数据与试飞记录。

### G.1 基础配置

**1．飞控有电、HUD正常，但所有舵机不动，先查PID吗？**

不查。先检查舵机电源、公共信号参考、输出安全状态、FUNCTION、物理输出映射、协议分组和指令是否到达。USB供电不意味着舵机电源轨已经供电。

**2．电机测试按钮A驱动了某电机，能直接认定它是Motor1吗？**

不能。测试字母与机架图中的测试顺序相关，必须对照当前frame定义和SERVO功能映射，无桨逐个核对物理位置和旋向。

**3．同型号飞控能否互相导入完整参数？**

不能默认安全。校准、设备ID、输出、接收机、电源、机体和外参可能不同。用对照表迁移可迁移的设计意图，重新校准与验收。

**4．为什么关掉所有PreArm检查不是“修好了解锁失败”？**

它消除了拒绝信号，没有消除被检测到的故障。下一步飞行仍可能面对错误姿态、电源、定位或执行器状态。

**5．一份4.6教程写WPNAV_SPEED=1200，把1200写进4.7的WP_SPD有什么问题？**

单位从cm/s改成m/s；物理意义差100倍。应先核对对应版本。即使数值超范围被拒绝，也不能依赖拒绝来防止全部迁移错误。

### G.2 通信与RTK

**6．115200 UART是否意味着115200 byte/s？**

不是。按8N1理想计算约11520 byte/s，实际还要考虑协议、无线调度、队列和重传。

**7．串口波特率正确、MAVLink仍不通，接着查什么？**

电平和TX/RX/GND、物理端口到SERIAL映射、协议、流控、串口占用、设备是否真的发数据，以及路由/系统ID。不能只反复换波特率。

**8．O4清楚而地面站卡顿，说明飞控CPU一定不够吗？**

不能。它们可能走不同链路。先检查MAVLink吞吐、RTCM竞争、射频干扰和供电，再检查调度/CPU证据。

**9．有两个GNSS接口，就能不用罗盘获得航向吗？**

不能。需要支持移动基线航向的设备、正确角色和链路、已知刚性基线及EKF源配置。

**10．同一个地面点三次RTK Fixed都很集中，就证明绝对误差2cm吗？**

只能说明在所用条件下重复性好；仍需独立真值、参考系和基站坐标证据才能评价绝对误差。

**11．基站Survey-in通过，却一直Float，如何缩小范围？**

分开确认有效RTCM产生、发送、飞控收到、rover收到并使用、共同星座/观测、修正龄期及接收机配置。Survey通过只覆盖第一部分。

**12．NAV30平均30Hz，为什么视觉仍无法插值？**

平均值掩盖长间隔；也可能时钟域、时间戳、顺序和队列不匹配。v11需要相应时刻的两个odom样本满足间隔条件，不仅要求平均率。

### G.3 控制与自动调参

**13．姿态跟踪很好，但飞机沿桶周围绕圈，应先增加D吗？**

先查航向、定位、坐标变换、上层目标和外环。没有证据表明角速度环阻尼不足，就不应先改D。

**14．为什么机械振动应先于AutoTune处理？**

辨识过程依赖有效测量；振动、裁剪与噪声会污染判断。滤波也不能还原已经丢失的数据。

**15．Lua QuickTune的GAIN_MARGIN=60表示保留60%吗？**

不是。检测到振荡时计划减少60%、保留40%，还要经过基线最大降低、yaw上限等约束。

**16．初始P=0.10、振荡点0.12，回退60%、最大降低20%，教学约束结果是多少？**

计划0.048；初始基线下限0.08；在没有其他限制的该算例中结果为0.08。

**17．DOUBLE_TIME=10，20秒无暂停理想增长到几倍？**

4倍。它是指数增长，不是每10秒加同一固定数值；实际脚本有阶段、上下界和暂停条件。

**18．QUIK_ANGLE_MAX=10是否禁止飞机任何时候倾斜超过10°？**

不是。该脚本检查目标姿态与实际姿态的误差角。飞机能以更大目标倾角飞而误差仍小；任务RELEASE的绝对roll/pitch门限是另一项。

**19．Lua整定中动摇杆，是否立刻回到原PID？**

该固定源码仅据此暂停继续整定并等待约4秒，不能认定全部参数自动恢复。应按专用LOW中止流程处理需要回退的情况。

**20．Lua出现DONE，落地上锁后参数消失，可能是什么？**

没有按Lua流程在落地前切HIGH保存。不要把内置AutoTune接受后落地保存的路径套过来。

**21．为什么QUIK_ENABLE=0不是可靠的空中回退按钮？**

固定源码在ENABLE分支直接返回，可能还没有运行恢复旧参数分支。已经写入RAM的候选增益可能保留。

**22．pcall成功捕获异常后，参数事务是否自动撤销？**

不会。pcall不是数据库事务；这份wrapper记录错误并安排重试，没有统一撤销此前改动。

**23．只调roll/pitch却看到yaw SMAX变化，是不是一定串轴？**

不一定。固定Lua的setup_SMAX遍历所有轴，为没有设置SMAX的轴补默认值。要读源码和差异，而非只看AXES推断写入范围。

**24．QWIK和QUIK只有拼写不同吗？**

不是。对应内置C++与Lua机制，参数名、默认值、禁用/模式保护都有实际差异。不能互相套用保证，也不要同时运行。

### G.4 任务验收

**25．12m/s、3m/s²减速到0，忽略其他因素需要几米？**

24m；若先有0.2s延迟，增加2.4m，合26.4m；还没加工程安全裕度。

**26．30m静止到静止、速度上限12m/s、a=3m/s²，能全程12m/s吗？**

不能。理想峰速约9.49m/s，总时间约6.32s，尚未计jerk和实际跟踪。

**27．连续10个20Hz好样本一定代表稳定0.5秒吗？**

相邻规则间隔下，第1到第10只跨0.45秒；若中间还有数据空洞，更不能按样本数证明连续稳定。

**28．水平速度很低、出瓶口几何误差很小，就能证明命中桶吗？**

不能。还有测量偏差、机构延迟、瓶子运动、风、桶口几何与实际第一落点。几何门限是允许动作条件的一部分。

**29．空载整定很好，双瓶和单瓶还要测什么？**

推力余量、输出饱和、重心偏移、结构摆动、释放瞬态、垂向恢复、低电量行为；单瓶A1/A2分别验证。

**30．任务进程死了但MAVROS仍发心跳，GCS失联保护一定会触发吗？**

不能保证。还要看心跳来源、飞控识别的系统、协议路由和其他发送者。应验证setpoint新鲜度与任务进程健康，而非只依赖连接图标。

### G.5 综合作业

提交一个不含真机控制指令的“飞控放行资料夹”：完整身份表、端口图、参数差异报告、RTK数据统计、一次调参操作流程选择题、12m/s制动预算、失效保护矩阵和未验证清单。

评分重点是证据与推理是否一致，不是参数列表是否长。对无法确定的字段明确写“未知、待实测”，比填入另一台飞机的数字更合格。

## 附录 H. 官方资料与固定版本源码

**查阅日期：2026-09-05。**网页可能随以后版本更新；不把日后master或网页默认值混入本文固定源码的结论。下列S项为官方项目文档、协议规范或设备厂商文档；G项为官方仓库源文件、发布或维护者记录。未将这些第三方页面全文打包为本地镜像。

本教程的大量算例、工作单、故障拆解和测试代码为针对本任务编写的教学内容，不是官方推荐的统一飞行参数。事实来源不一致时，正文明确指出；最终还须匹配实际构建、硬件与实测。
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

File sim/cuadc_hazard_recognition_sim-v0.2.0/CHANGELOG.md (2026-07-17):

# Changelog

## 0.2.0 — 2026-07-17

- Replaced known-bucket point-to-point flight with public-area-only lawnmower coverage.
- Added 7-lane, 14-endpoint coverage of the 5 × 8 m area.
- Added WGS84 → ECEF → RTK ENU → MAVROS local ENU conversion.
- Kept altitude control in MAVROS local Z.
- Added live OpenCV visualization and annotated image publishing.
- Added visual projection, centering and class-evidence accumulation.
- Added complete 10-class vectors, quarter-turn TTA and spatial deduplication.
- Separated Gazebo Server from Gazebo GUI.
- Added post-mission evaluation and explicit ground-truth isolation.
- Verified randomized seeds 4102, 4103 and 4104.
- Removed developer-machine defaults from the GitHub release.

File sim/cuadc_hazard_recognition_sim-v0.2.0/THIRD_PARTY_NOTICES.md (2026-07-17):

# Third-Party Notices

The project license does not override third-party terms.

## ArduPilot and MAVROS

ArduPilot SITL and MAVROS are runtime dependencies and are installed separately.

## ardupilot_gazebo Iris assets

`models/iris_d435i/` and `models/iris_d435i_airframe/` include modified model descriptions and Iris meshes derived from `ardupilot_gazebo`. The local source package declares GNU LGPL v3.0. Preserve upstream notices and verify the upstream repository when redistributing modified assets.

## Hazard marker textures

PNG files under `models/hazard_marker/materials/textures/` were prepared from CUADC competition attachment 11 material supplied for this project. They are included for competition simulation, research and training reproducibility.

The project does not claim these files as original artwork, and they are not automatically relicensed under LGPL-3.0-only. Before mirroring or commercial redistribution, verify the competition material's publication terms. If necessary, replace them with independently licensed textures while preserving filenames and class mapping.

## ONNX model

The trained `dangerous_target.onnx` is intentionally excluded. Users must provide a model for which they hold appropriate rights and set `CUADC_HAZARD_MODEL`.

ROS 2, Gazebo Sim, OpenCV, ONNX Runtime, yaml-cpp and NumPy retain their own licenses.

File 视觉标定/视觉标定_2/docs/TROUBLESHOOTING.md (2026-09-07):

# Troubleshooting

## ROS setup + `set -u`

症状：

```text
AMENT_TRACE_SETUP_FILES: unbound variable
```

原因：脚本启用了 `set -u`，ROS Humble setup 访问未定义变量。本包脚本已在 source 前自动 `set +u`，source 后恢复。

## D435i busy

```text
VIDIOC_S_FMT ... errno=16
Device or resource busy
```

检查：

```bash
pgrep -af "drop_bucket_realsense|realsense2_camera|vision_provider_template"
sudo fuser -v /dev/video* 2>/dev/null
```

不要重复启动视觉节点。

## web 8080 占用

```text
bind: Address already in use
```

检查：

```bash
pgrep -af web_video_server
ss -lntp | grep ':8080'
```

若已经是 web_video_server，直接复用。

## 浏览器无图

```bash
ros2 topic hz /cuadc/calib/annotated
```

没有频率先修视觉节点；有频率再检查 SSH 隧道/web server。

## 重复 ROS 参数声明

症状：

```text
ParameterAlreadyDeclaredException
```

检查：

```bash
python3 - <<'PY'
from pathlib import Path
import re
from collections import Counter
p=Path('~/cuadc_mission/src/cuadc_visual_drop_flight/scripts/drop_bucket_realsense_node.py').expanduser()
s=p.read_text()
names=re.findall(r'self\.declare_parameter\(\s*["\']([^"\']+)["\']',s)
for k,v in Counter(names).items():
    if v>1: print(k,v)
PY
```

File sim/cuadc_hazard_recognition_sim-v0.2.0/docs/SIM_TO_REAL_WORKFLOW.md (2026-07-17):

# 从区域覆盖仿真到实机危险物侦察

本流程只覆盖危险物侦察。

## 1. 任务信息隔离

实机状态机只能获得竞赛规定的侦察区域边界、RTK 基站和飞机状态，不能获得桶位。

仿真中的随机桶位真值只能用于：

- 生成 Gazebo 场景。
- 任务结束后评分。
- 分析模型误差。

不能把 `recon_targets`、桶编号或类别传入飞行状态机。

## 2. 覆盖航线

状态机根据公开区域边界生成往复式航线。航带间距必须小于实机相机在侦察高度下的有效横向地面覆盖宽度，并留出图像畸变、姿态误差和 RTK 误差余量。

实机前需要标定：

- 侦察高度下相机的有效地面覆盖 X/Y。
- 相机光轴与机体 Z 的夹角。
- 图像 U/V 轴与 MAVROS 本地 ENU 的方向关系。
- 云台或机体偏航对图像投影的影响。

## 3. 发现后视觉居中

覆盖飞行中发现目标后，先利用检测框和相机内外参估算目标地面位置，再做短距离居中。只有实际进入接受半径并稳定后，才累计类别证据。

仿真使用等效地面覆盖做平面投影。实机应替换为：

~~~text
pixel + depth/ground-plane
  -> camera optical frame
  -> body frame
  -> MAVROS map ENU
~~~

如果没有可靠深度，可使用已知地面平面、飞行高度、相机内参和姿态做射线与平面求交。

## 4. RTK 基准

必须记录：

- RTK 基站 WGS84 纬度、经度和椭球高。
- 同时刻的飞机 NavSatFix。
- MAVROS 本地 ENU 位姿。
- RTK ENU 到 MAVROS ENU 的水平偏航角。

水平位置通过 WGS84 -> ECEF -> 基站 ENU -> MAVROS ENU 转换。

不要把 RTK 基站高程或 GNSS 高程直接写入 MAVROS 本地 Z。垂直控制继续使用本地里程计和相对起飞高度；只有完成 geoid/ellipsoid、天线杆高和本地原点校准后，才能融合绝对高程。

## 5. 双可视化

地面调试默认保留：

- Gazebo/实机地面站态势窗口。
- OpenCV 实时识别窗口。

窗口不属于控制闭环。关闭 OpenCV 窗口不能停止推理或飞行。无人值守部署应关闭 GUI 后做一次完整回归。

## 6. 模型数据

重点补充：

- 同一类别在顺/逆时针旋转下的样本。
- 有毒品与自燃物品的 hard negative。
- 桶内偏移、边缘视角、运动模糊和不同曝光。
- 空桶、桶壁、地面纹理和其他标识。
- 视觉居中前后的尺度变化。

验证时分别统计目标发现率、空间定位误差、类别准确率和空区域误报，不要只看最终总分。

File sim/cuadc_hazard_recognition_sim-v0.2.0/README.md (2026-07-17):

面向 CUADC 危险物侦察任务的独立开源仿真包。项目基于 ROS 2、Gazebo Sim、ArduPilot SITL、MAVROS 和 ONNX Runtime，实现未知桶位条件下的区域覆盖搜索、RTK 坐标转换、实时视觉识别与 C++ 飞行状态机。

> 本仓库只包含危险物侦察仿真，不包含物资运输、投放或救援全流程。

60a32efd60bd4eb9bf699f835551e11b
4bcebf6ec7e6251e82e609225eed04ba

## 功能特点

- 未知桶位搜索：状态机只读取公开识别区域，不读取随机桶坐标。
- 区域完整覆盖：默认在 5 × 8 m 区域生成 7 条往复式航带、14 个覆盖端点。
- 随机场景：每个 seed 随机生成桶位置、危险物类别、标牌朝向、尺度与中心偏移。
- 真实视觉接入：ONNX 模型直接处理实时 ROS 图像，输出检测框、10 类置信度和标注图像。
- 主动视觉确认：发现候选目标后投影目标位置、短距离居中并累计类别证据。
- RTK 坐标链：WGS84 → ECEF → RTK 基站 ENU → MAVROS 本地 ENU。
- 双可视化：Gazebo GUI 和 OpenCV 实时识别窗口默认同时打开。
- 真值隔离：随机目标真值不会进入状态机，只在任务完成后由独立评分器读取。

## 系统结构

```mermaid
flowchart LR
    A["随机场景生成器"] --> B["Gazebo Sim Server"]
    B --> C["实时相机图像"]
    C --> D["ONNX 视觉节点"]
    D --> E["C++ 覆盖侦察状态机"]
    E --> F["MAVROS"]
    F --> G["ArduPilot SITL"]
    G --> B
    B --> H["Gazebo GUI"]
    D --> I["OpenCV 实时窗口"]
    E --> J["observations.json"]
    A --> K["任务后独立评分器"]
    J --> K
```

仿真默认使用 Gazebo 相机图像生成与载机位置对齐的实时 ROI，再交给与实机相同的 ONNX 节点。视觉节点消费标准 `sensor_msgs/Image`；接入机载 D435i 时只需替换图像话题并重新标定相机参数。

## 仓库结构

```text
cuadc_hazard_recognition_sim/
├── src/recon_state_machine_cpp.cpp      C++ 覆盖侦察状态机
├── scripts/hazard_vision_node.py        ONNX 推理与 OpenCV 窗口
├── scripts/generate_scene.py            随机场景生成
├── scripts/evaluate_coverage_result.py  任务后独立评分
├── scripts/run_hazard_coverage_once.sh  一键完整仿真
├── launch/hazard_recognition.launch.py  Gazebo/ROS 2 启动文件
├── config/                              场景、相机与 RTK 配置
├── models/                              Gazebo 模型及标识纹理
├── worlds/                              Gazebo 世界
├── examples/seed_4104/                  精简复现实验结果
└── docs/SIM_TO_REAL_WORKFLOW.md          实机迁移说明
```

## 已验证环境

- Ubuntu 22.04
- ROS 2 Humble
- Gazebo Sim 8.13.0
- ArduPilot Copter SITL 和 ardupilot_gazebo
- MAVROS
- Python 3、OpenCV、NumPy、ONNX Runtime
- C++17、yaml-cpp

Gazebo Sim 和 ArduPilot 插件版本必须相互兼容。当前完整测试使用 `ArduPilotPlugin` 和 JSON SITL 后端。

## 安装

### 1. 系统依赖

```bash
sudo apt update
sudo apt install -y \
  ros-humble-desktop \
  ros-humble-mavros ros-humble-mavros-extras \
  ros-humble-ros-gz-bridge ros-humble-cv-bridge \
  python3-opencv python3-numpy python3-pip python3-yaml \
  libyaml-cpp-dev
python3 -m pip install --user -r requirements.txt
```

还需要预先安装并构建 ArduPilot、ardupilot_gazebo 和对应的 Gazebo Sim。默认路径分别为 `~/ardupilot` 和 `~/ardupilot_gazebo`，也可设置：

```bash
export ARDUPILOT_DIR=/path/to/ardupilot
export ARDUPILOT_GAZEBO_DIR=/path/to/ardupilot_gazebo
```

### 2. 放入 ROS 2 工作区

```bash
mkdir -p ~/cuadc_ws/src
cd ~/cuadc_ws/src
git clone <YOUR_GITHUB_REPOSITORY_URL> cuadc_hazard_recognition_sim

cd ~/cuadc_ws
source /opt/ros/humble/setup.bash
rosdep install --from-paths src --ignore-src -r -y
colcon build --symlink-install --packages-select cuadc_hazard_recognition_sim
source install/setup.bash
```

### 3. 配置视觉模型

ONNX 权重不包含在仓库中。请设置：

```bash
export CUADC_HAZARD_MODEL=/absolute/path/to/dangerous_target.onnx
```

模型输出类别顺序必须与 `scripts/hazard_vision_node.py` 中的 `CLASS_NAMES` 一致。模型缺失时一键脚本会在启动前报错。

## 运行

默认同时打开 Gazebo 和 OpenCV 窗口：

```bash
cd ~/cuadc_ws
export CUADC_HAZARD_MODEL=/absolute/path/to/dangerous_target.onnx
bash src/cuadc_hazard_recognition_sim/scripts/run_hazard_coverage_once.sh 4104
```

更换最后一个数字即可生成新的随机桶位和类别。无人值守回归：

```bash
CUADC_SHOW_GAZEBO_GUI=false \
CUADC_SHOW_VISION_WINDOW=false \
bash src/cuadc_hazard_recognition_sim/scripts/run_hazard_coverage_once.sh 5201
```

完整的路径覆盖方式：

```bash
CUADC_WS=$HOME/cuadc_ws \
ARDUPILOT_DIR=$HOME/ardupilot \
ARDUPILOT_GAZEBO_DIR=$HOME/ardupilot_gazebo \
CUADC_HAZARD_MODEL=$HOME/models/dangerous_target.onnx \
bash src/cuadc_hazard_recognition_sim/scripts/run_hazard_coverage_once.sh 5201
```

## 输出

每次运行保存在 `~/cuadc_ws/cuadc_outputs/hazard_runs/seed_<seed>/`：

- `observations.json`：状态机原始输出，包含 `state_machine_has_ground_truth=false`。
- `result.json`：任务结束后的独立评分结果。
- `mission.log`：RTK、覆盖航线、视觉居中和状态转换。
- `vision.log`：ONNX 推理与 OpenCV 窗口日志。
- `generated_scene.yaml`：本次随机场景和评分真值。
- `frames/`：按间隔保存的原始及标注图像。

`examples/seed_4104` 保存精简通过样例，不包含大体积日志。

## 覆盖航线

| 参数 | 默认值 | 说明 |
|---|---:|---|
| 区域尺寸 | 5 × 8 m | 公开侦察区域 |
| 飞行高度 | 1.5 m | MAVROS 本地相对高度 |
| 航带间距 | 0.70 m | 小于相机横向覆盖 |
| 航带数 | 7 | 往复式排列 |
| 覆盖端点 | 14 | 每条航带两个端点 |
| 端点接受半径 | 0.30 m | 三维到达判定 |
| 相机地面覆盖 | 1.02 × 1.80 m | 当前等效值 |
| 视觉居中超时 | 5 s | 超时后恢复覆盖 |
| 类别证据窗口 | 3 s | 居中后累计 |

起飞点到首个覆盖端点是进场段。只有实际到达首端点后才启用识别记账，避免区域外纹理形成误报。

## RTK 与坐标变换

工程区分 `gazebo_world_enu`、`rtk_base_enu` 和 MAVROS `map_enu`。有效 `NavSatFix` 进入状态机后执行：

```text
WGS84 geodetic -> ECEF -> RTK base ENU
-> horizontal yaw alignment -> MAVROS local ENU
```

RTK 负责水平对齐；飞行高度始终使用 MAVROS 本地 Z，避免混淆椭球高、海拔高、天线杆高和飞控本地原点。

实机部署前必须测量基站坐标及天线高、识别区域相对基站的位置与朝向、相机外参和 RTK/MAVROS 水平偏航差。详见 [实机迁移说明](docs/SIM_TO_REAL_WORKFLOW.md)。

## 真值隔离

`generated_scene.yaml` 包含公开区域和仿真评分真值，但 C++ 状态机只解析识别区域、RTK 基站和载机初始参考，明确不读取 `recon_targets`。评分器只在任务生成 `observations.json` 后读取真值并空间匹配。

## 仿真结果

| seed | 覆盖 | 分类 | 空桶误报 | 结果 |
|---:|---:|---:|---:|---|
| 4102 | 14/14 | 5/5 | 0 | 通过 |
| 4103 | 14/14 | 4/5 | 0 | 有毒品/自燃物品边界混淆 |
| 4104 | 14/14 | 5/5 | 0 | 通过 |

seed 4104 的三个目标定位误差为 0.071–0.160 m。seed 4103 中全部目标位置均找到，剩余错误属于 ONNX 类别边界，没有通过类别特例或读取真值修正。

## 已知限制

- ONNX 权重由使用者提供，仓库不能保证不同模型的精度。
- 默认 ROI 相机适配器用于稳定复现；真实机载相机需要重新标定投影参数。
- 默认 RTK 基站坐标是 ArduPilot SITL 测试坐标，实机必须替换。
- 当前只验证单机、单实例端口 9012。
- 纹理和 Iris 网格有独立来源说明。

## 开发验证

```bash
source /opt/ros/humble/setup.bash
colcon build --packages-select cuadc_hazard_recognition_sim
python3 -m py_compile scripts/*.py launch/*.py
bash -n scripts/*.sh
```

贡献说明见 [CONTRIBUTING.md](CONTRIBUTING.md)。

## 许可证

原创代码以 [GNU LGPL v3.0 only](LICENSE) 发布。第三方网格和竞赛标识纹理不自动适用代码许可证，参见 [THIRD_PARTY_NOTICES.md](THIRD_PARTY_NOTICES.md)。

当前归档：`v0.2.0`，2026-07-17。

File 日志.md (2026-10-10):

# 2026 CUADC 备赛日志

> 这个日志偏向于日记，感兴趣的可以看一下，更为精简、偏技术路线的日志也会发布。

寒假培训之后并没有开展特别多的工作。电脑配置了一套往年的双系统，配置过程相对顺畅，但是在使用过程中非常难受。由于 Ubuntu 22.04 对网卡驱动有一定的要求，而我的电脑正好是那一代无法使用的，解决方法只有更换电脑网卡，遂直接更换为今年赛季的驱动，配置正式升级为 Ubuntu 22.04、ROS 2 Humble。

年前依靠大创组里面充足的经费（乐），拿到了两个 X7 飞控，进行了基础的学习，主要学了固件的烧写和与机载电脑的通信原理。年前也相对系统地学习了一下 ROS 2，看了半本书和几节课，都是鱼佬的。鱼佬的课的特点是 Python 和 C++ 同时展开讲解，Python 那个方便理解，毕竟代码简单，但是我们比赛还是用 C++，下个学期的专业课正好是这个，就一起学了。

## 2026.02.16

新年快乐，ChatGLM 开放了 Agent 模式，探索性使用过后觉得非常好用，在后续的备赛阶段要批判地使用。

## 2026.02.18

搞了两天的 Gazebo 仿真（参考往年技术文档中的“如何在 Gazebo 中自定义模型与地图”），并配合 ChatGLM 完成了一份比较清晰的技术文档，方便新会员使用和学习。这个仿真的技术路线还是比较清晰的。当基础仿真环境搭建好之后，接下来的任务就是导入三个模型插件：“世界插件”“模型插件”“传感器插件”（传感器插件我不确定用不用）；鉴于我们的飞控固件选择，我们需要在仿真环境导入 APM 固件，在“ROS2_Humble_Gazebo_APM 无人机仿真配置教程”中第四节有详细解读。

- **SDF（Simulation Description Format）** 是 Gazebo 使用的模型描述格式，定义了机器人的物理结构、视觉外观和传感器配置。在 Windows 系统中并没有发现可靠的、可以预览这个格式文件的软件（CSDN 说可以用什么 vismod 来看，但是我这边下载了也打不开）。另一个莫名其妙的事是，我电脑上默认打开 SDF 文件的软件居然是我的 Altium Designer。当然，在 ROS 环境中就简单多了，ROS 自带的 RViz 可以预览 SDF 文件。
- **MAVROS** 是 MAVLink 协议的 ROS 接口，用于实现 ROS 与 ArduPilot 之间的通信，是一个比较重要的通信模块。MAV 就是“micro air vehicle”的缩写，代表微型航空器。这个过程在文档 5.3 节有说明。
- 另一个重要的模块是 Blender 的使用，它可建模、可贴图，还支持 Ubuntu，所以比较友好。去年的技术文档里面有现成的模型，直接使用就好了。
- 我们要验证的飞行代码是 `code1.cpp`（没找到的看这里：`多旋翼无人机技术文档\状态机代码\cadc_quad_state_machine\src\code1.cpp`）。接着按照文档里面的做就行。我们验证自己的代码，不用管文档中那一段。当然了，要是有更好的想法，也可以重新写一下。

- 发现 Gazebo 仿真的版本问题：如果你的 `cmake ..` 一直报错，大概率是没有指定 Gazebo 版本，新的文档更改了这个地方。
- 建议双系统安装微信，在浏览器里面搜微信就行，选择 Linux 的微信，一般都是 x86 架构，不放心就用 `uname -m` 查一下，然后选择 `.deb` 格式的软件包（适用于 Ubuntu）。在下载目录下打开终端，用 `sudo dpkg -i 你的压缩包名称` 命令安装。
- 别忘了你的 AI 在双系统里面同样可以使用。

## 2026.02.19

ChatGLM 写的文档有很多问题，目前 Gazebo 仿真停滞。重新更正错误后，仅出现了一个好的画面，包括简化的 Gazebo 模型、飞控信息和地图。

### 一、今日操作中遇到的全量问题汇总

结合今日完整操作链路与报错信息，遇到的问题可分为 6 大类，均为仿真环境搭建与代码验证的核心阻塞点，具体如下：

#### 1. 飞控与仿真通信核心链路完全失效，持续 `link 1 down`

- **核心现象**：ArduCopter 飞控程序启动后，始终显示 `link 1 down`，无法与 Gazebo 仿真环境建立 UDP 通信，无法获取传感器数据，飞控无法完成 EKF 初始化、GPS 锁定，最终停留在 `Waiting for connection` 状态，无法进入可飞行状态。
- **直接诱因**：教程启动时序设计错误，引导先启动飞控再启动 Gazebo，飞控发起 9002/9003 端口连接时，Gazebo 还未完成端口监听，且教程未说明飞控的重连机制，导致链路永久断开。

#### 2. Gazebo 仿真启动完全异常，模型加载持续失败

- **现象 1：Gazebo 窗口完全无法弹出**：执行教程 4.3 节的 `sim_vehicle.py` 一键启动命令后，无任何 Gazebo 可视化窗口弹出，仅飞控程序单独运行。
- **现象 2：模型显示异常**：手动启动 Gazebo 后，仅能显示简化圆柱体机身，无法加载官方 iris 四旋翼完整模型，无旋翼、机身 3D 结构。
- **现象 3：启动报错频发**：Gazebo 启动时持续出现 `Plugin not found`、`模型找不到`、`Unable to find shader lib` 等红色报错，插件与渲染资源加载完全失败。
- **核心根源**：教程未说明 `sim_vehicle.py` 脚本拉起 Gazebo 强依赖 `run_gazebo.sh` 启动脚本，既未提供该脚本的创建方法，也未说明模型/插件的路径配置规则。

#### 3. ROS 2 工作空间 `colcon` 编译全链路失败，多次触发致命报错

- **问题 1：重复功能包名冲突**：`colcon` 检测到 `ardupilot_dds_tests`、`ardupilot_msgs`、`ardupilot_sitl` 等 ROS 包，在工作空间根目录和 `src/` 目录下重复存在，直接终止编译。
- **问题 2：依赖缺失编译失败**：`ardupilot_sitl` 包编译时提示 `Could not find the program ['microxrceddsgen']`，教程完全未提及该 DDS 依赖的安装步骤。
- **问题 3：权限不足编译终止**：`ardupilot_sitl_gazebo` 插件编译时，触发 `Permission denied` 报错，无法向 `/usr/lib/` 系统目录复制插件文件，编译直接失败。
- **核心根源**：教程违背 ROS 2 工作空间官方规范，错误引导将 ArduPilot 固件源码、ArduPilot_Gazebo 系统插件放入 ROS 2 工作空间 `src/` 目录，导致 `colcon` 递归扫描编译时出现一系列冲突与权限问题。

#### 4. 环境变量配置持续报错，`bashrc` 终端环境加载失效

- **问题 1：语法错误导致路径完全失效**：教程 4.2 节的 `GAZEBO_MODEL_PATH` 配置存在文本截断，复制后导致 bash 语法错误，路径无限循环叠加，每次加载 `bashrc` 都会触发 `没有那个文件或目录` 报错。
- **问题 2：无容错处理的 `source` 命令**：教程 2.4 节引导将 `source ~/drone_sim_ws/install/setup.bash` 直接写入 `bashrc`，但未做文件存在性判断，删除 `install` 目录后，每次打开终端都会触发文件不存在报错。
- **问题 3：路径配置不严谨**：教程 4.1 节的 ArduPilot 环境变量路径未做严格校验，路径变更后直接触发补全脚本找不到的报错。
- **问题 4：加载优先级完全错误**：教程先配置自定义模型/插件路径，再加载 Gazebo 官方 `setup.bash`，导致自定义路径被官方脚本覆盖，Gazebo 永远找不到模型和插件。

#### 5. 模型与世界文件持续缺失，教程引导的操作完全无法执行

- **核心现象**：按教程引导从 ArduPilot_Gazebo 仓库复制 `iris` 模型和 `iris.world` 世界文件时，持续触发 `没有那个文件或目录` 报错，复制操作完全无法执行。
- **根源**：ArduPilot_Gazebo 官方仓库内，带完整 ArduPilot 插件配置的模型名为 `iris_with_ardupilot`、世界文件名为 `iris_with_ardupilot.world`，教程完全未说明该命名差异，也未提供重命名步骤，与仓库实际内容完全不符。

#### 6. 自动飞行代码验证的前置环境始终无法就绪

- **核心现象**：仿真全链路始终无法打通，MAVROS 无法与飞控建立心跳连接，`/mavros/state` 话题始终显示 `connected: false`，无法进入 C++ 自动飞行代码的验证环节。
- **根源**：教程 6.2 节的启动流程未明确各终端的启动等待条件，未说明必须等飞控显示 `Ready to FLY` 后才能启动 MAVROS，用户按教程顺序执行时，飞控未初始化完成就启动 MAVROS，必然导致连接失败。

---

### 二、教程中存在的所有错误与设计缺陷

结合教程原文与实际操作结果，该教程存在 **4 大类、14 项致命错误与设计缺陷**，是你今日所有问题的核心根源，具体如下：

#### 一、致命文本截断与语法错误，直接导致环境完全失效

1. **4.2 节 Gazebo 环境变量存在致命文本截断**

   教程原文给出的配置：`export GAZEBO_MODEL_PATH=$ARDUPILOT_ROOT/Tools/simulation/gazebo-classic/models:$HOME/drone_sim_ws/src/ArduPilot_Gazebo/models:$GAZE`

   - 错误点：行尾 `$GAZE` 是 `$GAZEBO_MODEL_PATH` 的严重文本截断，用户复制后直接触发 bash 语法错误，路径配置完全失效，Gazebo 永远找不到模型和插件，这是你环境变量报错的核心根源。
   - 附加错误：教程完全未说明环境变量的加载优先级，必须先加载 Gazebo 官方 `setup.bash`，再配置自定义路径，否则自定义路径会被官方脚本覆盖，教程的配置顺序完全颠倒。

2. **`bashrc` 配置无任何容错处理**

   教程 2.4 节、4.1 节引导将 `source ~/drone_sim_ws/install/setup.bash`、ArduPilot 补全脚本的 `source` 命令直接写入 `bashrc`，但未添加任何文件存在性判断。

   - 错误点：当用户删除 `install` 目录、或 ArduPilot 路径变更时，每次打开终端都会触发 `没有那个文件或目录` 的报错，直接导致终端环境失效，教程完全未考虑该高频容错场景。

#### 二、违背官方规范的设计错误，直接导致编译全链路失败

1. **错误引导 ArduPilot 固件的存放位置，违背 ROS 2 工作空间规范**

   教程 4.1 节引导将 ArduPilot 固件源码克隆到 `~/drone_sim_ws/src/` 目录（ROS 2 工作空间源码目录），这是完全违背官方规范的操作。

   - 错误点：ArduPilot 固件内部 `Tools/ros2/` 目录下自带多个 ROS 2 功能包，教程完全未说明需要添加 `COLCON_IGNORE` 文件让 `colcon` 跳过编译，直接导致你执行 `colcon build` 时出现重复包名、依赖缺失、编译失败等一系列问题。
   - 官方规范：ArduPilot 固件应使用 `waf` 工具独立编译，禁止放入 ROS 2 工作空间 `src` 目录被 `colcon` 扫描。

2. **错误引导 ArduPilot_Gazebo 插件的编译安装方式**

   教程 4.2 节先引导将 ArduPilot_Gazebo 克隆到 `~/drone_sim_ws/src/` 目录，再用 `cmake` + `make` + `sudo make install` 安装，完全违背 ROS 2 与 Gazebo 插件的安装规范。

   - 错误点 1：放入 `src` 目录后，`colcon` 会将其识别为 ROS 功能包，但其 `CMakeLists.txt` 的安装目标是系统级目录 `/usr/lib/`，普通用户执行 `colcon build` 无 `sudo` 权限，直接触发 `Permission denied` 编译失败。
   - 错误点 2：教程未说明该插件是 Gazebo 系统级插件，应放在 ROS 工作空间外单独编译安装，而非放入 `src` 目录，这是你插件编译失败的直接原因。

3. **缺失关键依赖的安装说明**

   教程完全未说明编译 ArduPilot 内置 ROS 2 包需要 `microxrceddsgen` DDS 代码生成工具，也未提供该依赖的安装步骤，用户直接编译必然触发 `Could not find the program ['microxrceddsgen']` 报错。

#### 三、关键流程与依赖缺失，导致仿真启动必然失败

1. **核心启动脚本完全缺失，未做任何说明**

   教程 4.3 节直接给出 `sim_vehicle.py` 一键启动命令，但完全未说明该命令拉起 Gazebo 强依赖 `Tools/simulation/gazebo-classic/run_gazebo.sh` 脚本，既未提供脚本的创建方法，也未提及该脚本的存在。

   - 错误点：用户按教程执行命令后，`sim_vehicle.py` 无法拉起 Gazebo，直接导致 Gazebo 窗口不弹出、飞控启动后无仿真器连接，永久 `link 1 down`，这是你核心问题的根源。

2. **启动时序完全错误，未明确关键等待条件**

   教程 6.2 节给出了多终端启动流程，但完全未明确每个步骤的等待条件：必须等终端 1 飞控显示 `Ready to FLY`、完成 EKF 初始化与 GPS 锁定后，才能启动终端 2 的 MAVROS 节点。

   - 错误点：用户按教程顺序执行，未等飞控初始化完成就启动 MAVROS，必然导致 MAVROS 无法连接飞控，教程缺失关键的启动时序与分步成功标志说明。

3. **模型/文件命名与官方仓库实际内容完全不符**

   教程 4.2 节、5.2 节、5.3 节均引导使用 `iris` 模型和 `iris.world` 世界文件，但 ArduPilot_Gazebo 官方仓库内，带完整 ArduPilot 插件配置的模型名为 `iris_with_ardupilot`，世界文件名为 `iris_with_ardupilot.world`。

   - 错误点：教程完全未说明该命名差异，也未提供重命名步骤，用户按教程执行 `cp` 命令必然触发 `没有那个文件或目录` 报错，导致模型加载失败。

4. **缺失高频场景的前置清理步骤**

   教程所有启动步骤前，均未提供残留进程清理命令，用户反复启动仿真时，`gzserver`、`arducopter`、`mavproxy.py` 等进程残留，会占用 9002/9003/5760 等核心端口，直接导致仿真启动失败、link 1 down，教程完全未考虑该高频故障场景。

5. **缺失 MAVProxy 前置安装步骤**

   教程 4.3 节的 `sim_vehicle.py` 脚本强依赖 MAVProxy 地面站工具，但教程完全未提前说明 MAVProxy 的安装方法，用户执行脚本会直接触发 `mavproxy.py: 未找到命令` 报错，仿真启动直接中断。

#### 四、版本兼容与细节缺失，埋下大量隐性故障

1. **未明确分支与版本的兼容性要求**

   教程 1.3 节推荐使用 Copter-4.5 稳定分支，但未说明该分支的 `Tools/simulation/gazebo-classic` 目录结构与 master 分支不同，部分子模块文件缺失，也未提供文件补全方法；同时未明确 ArduPilot_Gazebo 仓库与 ArduPilot 固件分支的匹配要求，用户克隆 master 分支插件后，与 Copter-4.5 固件存在兼容性问题。

2. **未提及 Gazebo 与 Wayland 协议的兼容问题**

   教程完全未提及 Ubuntu 22.04 默认的 Wayland 显示协议与 Gazebo 11 存在严重渲染兼容问题，会导致 Gazebo 黑屏、窗口崩溃、shader 库找不到等问题，也未提供 `QT_QPA_PLATFORM=xcb` 的修复方案，用户遇到该问题时完全无排查方向。

3. **缺失分步验证环节，无法定位故障节点**

   教程仅给出最终的成功标志，未提供分步验证方法：比如先单独启动 Gazebo 验证模型/插件加载，再启动飞控验证通信链路，最后启动 MAVROS 验证 ROS 连接。用户一键启动失败后，无法定位是 Gazebo、飞控还是 MAVROS 的问题，排查完全无方向。

4. **未明确脚本的运行环境要求**

   教程 4.3 节仅说明要在 ArduPilot 根目录执行 `sim_vehicle.py` 脚本，但未明确必须用 `python3` 执行，也未说明脚本的运行依赖，用户在错误的环境、错误的路径执行时，会触发一系列无明确提示的隐性报错。

协会第一周安排了一下工作，并开始正式备赛。新会员的硬件经验较少，上手比较困难。开学早期的目标是使用树莓派完成自动飞行验证，旨在让新会员快速上手并熟悉 Linux 和 ROS。我这边准备用英伟达配一个好的仿真环境，来验证后续的代码，代码仿真的必要性还是有的。

## 2026.03.26

好久没写日志了，昨晚去惯导中心找了刘博老师，拿到了一些验证机和遥控器，也拿到了 1455 型号碳桨四对，可以在前期应用。开学到现在选了一套新的动力组，型号如下：

- SUNNYSKY X4112S 朗宇无刷电机 KV450
- 好盈 60A-V2【3S–6S 支持反推】电调
- 格氏 5300 mAh 30C 6S XT60 电池

和博哥聊过了之后，找到了一些备赛方向，决定这周就出外场让大家去调参、熟悉流程，预计两周验收参数。结构部分出了一版，本周完成动力组试车，下周大规模采购、装机。

**现有人员：**

- 视觉：罗\*\*、朱\*\*、李\*\*、刘\*\*、徐\*\*
- 状态机部分：姜\*\*、李\*\*、刘\*\*、阮\*\*
- 控制部分：李\*\*、逯\*\*

## 2026.03.29

一次组会。

### 现有进度

新动力组选取完成，预计下周二上试车台。验证了第一版自动飞行程序，飞矩形没有问题。3 月 28 日出了一次外场，原本目的是让调参的同学去上手调参，但是外场出现两个问题：一个是调参的同学不会使用地面站和数传，另一个是数传电台出现故障，在格物楼连接正常，在操场上无法连接，原因未查明。

调参的同学对整体流程的熟悉度不够，后续加强督促与引导。

自己采购失误，电调额定电流较大，用的是 4 mm 香蕉头，原本协会用的都是 3 mm 的，需要重新采购香蕉头并焊接。补充一下，去年的虽然是 50 A 电调，但是只支持 3S–4S 电池，不满足今年的 6S 动力需求。

### 下周规划

完成第一架整机组装，清明完成第一架整机试飞调参（不带抛投机构），主要目标是验证新的机械结构，顺利的话上机载电脑做一个简单的自动飞行。

### 补充一些飞行状态知识

- AltHold（高度保持）：飞行器会保持当前高度，飞行员通过遥控器控制前后左右移动。
- Stabilize（稳定模式）：最基础的飞行模式，飞行器会自动修正姿态，但不会保持高度或位置，完全由飞行员控制。
- Acro（筋斗/特技模式）：允许飞行器进行快速翻转和旋转，是进行特技飞行的模式。
- Auto（自动模式）：飞行器按照预先规划的航线自动飞行。
- Guided（引导模式）：可以通过地面站或遥控器手动引导飞行器飞向特定坐标点。
- Loiter（悬停模式）：飞行器会自动保持在当前位置和高度，是介于手动和自动之间的模式。
- RTL（返航模式）：飞行器会自动返航到起飞点并降落。
- Circle（环绕模式）：飞行器会以起飞点为中心进行环绕飞行。
- Land（降落模式）：飞行器会自动缓慢降落。
- Drift（漂移模式）：允许飞行器进行类似 FPV 竞速的漂移飞行。
- Sport（运动模式）：增强的稳定模式，响应更灵敏，适合快速飞行。
- Flip（翻转模式）：允许飞行器执行预设的翻转动作。
- AutoTune（自动调参）：飞行器在飞行中自动调整 PID 参数以优化性能。
- PosHold（位置保持）：飞行器会保持在特定的 GPS 位置和高度。
- Brake（刹车模式）：飞行器会立即停止前进并悬停。
- Throw（投掷起飞）：允许将飞行器像飞盘一样投掷出去以启动飞行。
- Avoid_ADSB（ADS-B 避障）：利用 ADS-B 信号进行空中交通避让。
- Guided_NoGPS（无 GPS 引导）：在没有 GPS 信号的情况下，通过地面站手动引导飞行器。
- Smart_RTL（智能返航）：在返航途中遇到障碍物时，会自动规划绕行路线。
- FlowHold（光流悬停）：在没有 GPS 的环境下，利用光流传感器保持悬停。
- Follow（跟随模式）：飞行器会跟随一个移动的目标（如遥控器或另一架飞行器）。
- ZigZag（之字形）：飞行器会按照预设的之字形航线飞行。
- SystemID（系统识别）：用于收集飞行数据以分析飞行器性能。
- Heli_Autorotate（直升机自旋）：直升机在失去动力时自动进行自旋降落。
- Auto_RTL（自动返航）：与 RTL 类似，但通常指在任务完成后自动返航。
- Turtle（翻滚模式）：允许飞行器进行类似乌龟翻滚的特技动作。

### 其他记录

- 桨叶最终选取型号为 1447。
- 与老轴子建立联系，共享技术与调参经验。

## 2026.05.08

好长时间没写文档了，借着五一大外总结一下这一阵子的工作情况：

### 队伍分组

仿照竞技机器人队分组方式，将队伍分为结构、控制和视觉三组。

### 视觉与控制进展

视觉方面，训练出危险物识别和圆筒识别两个模型。模型使用没有问题，控制部分由两位控制同学进行飞控设置和调参，在前期遇到较大问题。控制同学对 AP 文档掌握不熟练，对地面站使用和内外环 PID 参数理解程度不足，完全信任 AI 的建议进行调参，导致第一架机参数异常，飞行异常抖动，甚至没有测试动力时使用的原始参数好用。第一次外场调试过后，飞机基本能稳定手动飞行，但是由于 RTK 信号缺失，无法使用 RTK 信号进行实时定位。第一次尝试飞行自动程序时，由于 GPS 信号定位不稳，飞机与原定航程的距离偏差巨大，为保证安全，最后切回手动降落。

### 在第一次飞机自动飞行中发现以下问题

开机自启脚本启动并不是非常顺利，后检查日志发现，开机自启脚本没有很好地运作，有报错。后改用 SSH 远程连接机载电脑，启动 ROS 节点。

备赛过程整体进度较为缓慢，主要问题出在控制方面，控制同学对飞控使用和地面站使用依旧不能很好掌握。

作为负责人，整体责任在于没有很好地给各个板块的进度留出自己托底的时间。大外前一天晚上，控制同学调出的新飞控报错极多，电机无法解锁（强解也不行），电调无法校准。五一大外前一天晚上临时花了 4 小时赶工，调出了无报错的飞控，但是使用的是控制同学的 AI 参数。前期外场出的次数少，各个板块跟进和协调没有做好，后续备赛过程将严肃改进。

### 新的硬件选型更新

- RTK：CUAV C-RTK 2HP
  - 产品页：<https://www.cuav.net/c-rtk-2hp/>
  - 用户手册：<https://doc.cuav.net/gps/c-rtk-series/zh-hans/c-rtk2-hp/users-manual.html>

- DC-DC：24 V → 19 V
- 机载电脑：Intel NUC

## 2026.05.17 外场

这次外场主要目的是测试摄像头和自动飞行代码。

本次测试对象：`offb_node.py`。自动飞行代码逻辑如下：

| 状态 | 行为 |
| --- | --- |
| `WAITING_FCU` | 等待飞控连接（检查 `/mavros/state` 的 `connected` 状态） |
| `SETTING_GUIDED` | 切换至 GUIDED 模式（调用 `SetMode` 服务） |
| `ARMING` | 解锁电机（调用 `CommandBool` 服务） |
| `TAKEOFF` | 起飞至 2 m（调用 `CommandTOL`，⚠️ 禁用 setpoint 发布） |
| `FLYING_WAYPOINTS` | 按航点飞行（发布 setpoint 位置控制） |
| `LANDING` | 降落（调用 `CommandTOL land`） |
| `DONE` | 任务完成，关闭节点 |

由于坐标变换问题，飞机实际飞行方向为：东 → 北 → 西 → 南；这跟 ArduPilot 原生的坐标轴定义有关，后续坐标变换问题将是一个比较重要的方向。

视觉代码验证出现失误，原因为侦测危险物的文件保存依赖 Ubuntu 图形化界面，而不能仅通过 SSH 中的终端来保存、打印，后续代码将改进这一问题。同时，由于现有飞机的飞行高度和动力问题，飞机飞到侦察桶上方会将侦察桶吹翻（），后续需要提升侦察高度。

**现有人员：**

- 视觉部分：朱\*\*、李\*\*、刘\*\*
- 控制部分：李\*\*、姜\*\*、李\*\*、王\*\*
- 机械部分：逯\*\*

### 仿真教学参考

#### 如何在 Gazebo 中自定义模型与地图？

在看这个文档之前，我想您已经构建了基本的 **“PX4 + MAVROS + Gazebo”** 无人机仿真环境。可以看到，其默认的“世界”是一个空旷的地图，这显然不是我们想要的效果。为了实现对比赛流程更好的仿真，我们将针对 **CRAIC** 的赛题要求在 **Gazebo** 中搭建地图。

---

**建模流程参考：**

- [（建模流程与文件系统设置）Gazebo 贴图模型制作与导入 - 式部二木的文章 - 知乎](https://zhuanlan.zhihu.com/p/454908515 "建模流程与文件系统设置")
- [（视频教程）【教程】Blender如何给正方体或其他物体贴图](https://www.bilibili.com/video/BV1kg411i7wV/?share_source=copy_web&vd_source=baa473962fcecb25dd3da2fb145239f6 '视频教程')
- [（补充）CSDN：贴图入门教程](https://blog.csdn.net/qq_22328011/article/details/130051296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 '补充')
- [（地图创建）机器人仿真-gazebo学习笔记（2）gazebo的使用和world创建](https://blog.csdn.net/weixin_75067193/article/details/134097825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)

---

##### 1. 使用工具

建模软件：[Blender](https://www.blender.org/ '下载链接')（可建模、可贴图、支持 Ubuntu）。

##### 2. 基本流程

###### 在 CAD 软件中搭建模型并导入

我们需要的模型有：正方形薄板（各种靶子），长方体柱形障碍，环状结构（钻圈）。

模型形状本身其实在 Gazebo 自带的模型设计功能中就能满足，但是为了视觉仿真的需要，我们需要对模型进行贴图。

具体流程请参考现有文献，不在此赘述。也没什么雷点，跟着视频教程做一遍就差不多了。现在其实往上贴的贴图本身有点问题：定量地画几个同心圆，涂上不同颜色，最后把图片靶放在中间，这个过程还没有实现。倒不是有多么复杂，只是现在没时间搞了，期待后人的智慧。另外，建模圆环的具体方式我忘记了，记得是用桥接面给圆柱体打孔实现的，以后有时间再补上吧。

导入方式第一篇文章里面有，写得很详细。

###### 在 Gazebo 中搭建世界

舍友在催我熄灯，时间关系不配图了，以后再补。

打开 Gazebo，直接在终端中输入 `gazebo` 就行，我们只是简单建个图。

看到左侧的选项卡，选 `Insert`，这个就是在插入我们的模型。

找到 `Add Path`，如果自定义的模型没有复制到 PX4 里面 Gazebo 默认的 `model` 路径的话，就用这个添加。

点击左侧 `Insert` 里面目录下的模型文件，就可以将模型添加到当前世界中。

如果点了自定义模型之后没反应，一般是我们构造 Gazebo 可识别的模型目录时出了问题。在构造目录的时候，不要修改图片名等信息，导出什么就直接复制进去。

我们想定量控制模型的位置，点击世界中的这个模型，左侧的选项卡会跳转到这个模型的相关参数。在 `Pose` 中可以更改它的 x、y、z 坐标与欧拉角，这个是模型中心的位置，更改为我们需要的位置即可。注意欧拉角是弧度制。

依照这个思路即可完成整个地图的构建。

导出时在 `File` 中使用 `Save World` 即可，记得输入文件名。

###### 将我们的模型添加到仿真启动文件中

我们启动仿真时，使用的 launch 文件为 `posix_sitl.launch`，我们要修改的就是这个文件。

这个文件在 PX4 文件夹中的 `launch` 文件夹中。

打开 `posix_sitl.launch`，找到：

```text
arg name="world" default="xxx"
```

把 xxx 换成地图所在的绝对路径即可。如我的地图名为 **“sample”**，放在主目录下的 **“CRAIC_world”** 文件夹中，那么我的参数就是 `/home/zxy（填自己的主目录路径）/CRAIC_world/sample`。

类似地，我们可以看到，也可以为插入其中的飞机模型的 x、y、z 坐标和姿态赋值。把飞机的位置放到我们起飞点即可。

这份文档只能说是一份半成品，仅供参考，希望其他同学可以对它进行补充修改。

## 2026.06.01 儿童节快乐（？）

今天是历史性时刻，第一次使用 RTK 基站完成了固定解收敛，但是并没有使用蘑菇头天线，原因是没有非常合适的线。

提示：RTK 定位状态中，Float（浮点解）和 Fix（固定解）的区别非常大，直接决定你的无人机定位精度，具体如下：

| 状态 | 中文 | 水平精度 | 是否满足高精度定位 |
| --- | --- | --- | --- |
| Single | 单点定位 | 1~3 m | ❌ |
| DGPS | 差分定位 | 0.3~1 m | ❌ |
| Float | 浮点解 | 0.1~0.5 m | ⚠️ 一般 |
| Fix | 固定解 | 1~3 cm | ✅ |

## 2026.06.05

又一次历史性时刻，首次使用蘑菇头天线完成定位收敛，并且翻遍了协会所有的五金件，搭建了天线三脚架。

RTK Fix 用时：`03.37.26`，感觉还是挺快的。

## 2026.06.13

今天用朱\*\*的大一年度项目机子完成了第一次室外实机自动起飞流程，效果不错，飞机自旋问题整体可以忽略，而且这个小飞机经过 AutoTune 调参，参数相对也不错。

值得注意的是，AutoTune 调参的前提是在 AltHold 模式下能基本实现稳定飞行；对于大飞机有相应的特殊需求，详见 <https://ardupilot.org/copter/docs/autotune.html>。

## 2026.06.16

今天配合 Codex 完成了全流程的仿真环境配置，方便后人学习使用，全套文件放进了 `cuadc_sim` 中。值得注意的是，本年备赛使用了 D435i 下视深度相机，如果后人的方案没有这一部分，请忽略。

并且做了一个仅有侦察危险物区域的环境，放入了 `cuadc_hazard_recognition_sim` 中。

## 2026.06.20

端午节外场。

端午节快乐（实际不快乐）。今天用大轴子完成了自动飞行，效果非常不好，原因是飞机会乱飞，而且参数是一大问题。

抛开参数问题不谈，在飞行原点定义上有很大问题。其中这一版代码定义的原点是 `/mavros/local_position/odom`，然后把当前位置里的 x/y/z 直接当作控制判断依据；同时一开始就把 `current_target_` 设成 `{0,0,0}`，并允许发布 setpoint。起飞完成后，代码又强制把目标设成 `{0,0,TAKEOFF_ALT}`，随后矩形航点是 `{0,0}` → `{5,0}` → `{5,5}` → `{0,5}` → `{0,0}`，这些都是绝对 local 坐标，不是“从起飞点开始的相对坐标”。

而在官方文档中，ArduPilot 的 `SET_POSITION_TARGET_LOCAL_NED` 不是“以当前解锁点为原点”，而是相对 EKF origin；官方文档写得很关键：`MAV_FRAME_LOCAL_NED` 的位置是相对 EKF Origin，EKF origin 是飞控第一次获得良好位置估计时的位置。

详细见：<https://ardupilot.org/dev/docs/copter-commands-in-guided-mode.html>

后续改进方案是：飞机准备起飞时或起飞完成后，读取一次当前 `/mavros/local_position/odom`，保存为：

```cpp
mission_origin_x = current_position_.x;
mission_origin_y = current_position_.y;
mission_origin_z = current_altitude_;
```

然后所有矩形航点都变成：

```cpp
target_x = mission_origin_x + rel_x;
target_y = mission_origin_y + rel_y;
target_z = mission_origin_z + TAKEOFF_ALT;
```

同时高度判断也不能写成：

```cpp
current_altitude_ >= TAKEOFF_ALT * 0.95
```

而应该写成：

```cpp
current_altitude_ - takeoff_start_z >= TAKEOFF_ALT * 0.95
```

同时，三次起飞时移动基站，甚至在飞行过程中移动基站，是严重的错误。

ArduPilot 的 RTK 文档明确说，RTK 成功的关键是基站位置必须被精确知道或通过 survey-in 确定；基站会把这个位置作为自己的位置开始输出改正数据。所以移动基站，会破坏这个前提。详见：

<https://ardupilot.org/copter/docs/common-rtk-correction.html>

如果移动了基站，机载 RTK 接收机可能出现这几种情况：

1. RTK Fixed 掉到 Float 或 3D Fix。
   - 飞控定位精度突然下降。

2. RTK 仍显示 Fixed，但位置整体偏了。
   - 这是更危险的情况。因为飞机会“很自信地相信一个错的位置”。

3. `/mavros/local_position/odom` 的 x/y 发生跳变。
   - 你们的状态机如果正在追踪 `{0,0}`、`{5,0}` 这类 local setpoint，飞机可能突然认为自己偏离目标，于是做大幅修正。

4. EKF 认为 GPS glitch / EKF variance 增大。
   - ArduPilot 的 GPS glitch 检测会把新的 GPS 位置和上一时刻位置、速度外推出来的位置做比较；如果差异异常，就可能触发 GPS glitch：<https://ardupilot.org/copter/docs/gps-failsafe-glitch-protection.html>
   - EKF failsafe 文档也说明，如果 GPS 位置突然跳了，但加速度计没有对应的运动，EKF 的位置可信度会变差：<https://ardupilot.org/copter/docs/ekf-inav-failsafe.html>

5. GUIDED / Loiter / Auto 这类依赖 GPS 的模式会变得危险。
   - ArduPilot 说明，在 Guided、Auto、Loiter、RTL 等需要 GPS 的模式下，如果 GPS 锁定丢失或位置 glitch 持续，会触发 GPS failsafe：<https://ardupilot.org/copter/docs/gps-failsafe-glitch-protection.html>

而在以往的飞行中，GPS 3D 定位涉及不到这一问题，所以没有出现这样严重的飞机乱飞情况。

下次外场根据本次错误进行新的代码调试，规范地面 RTK 基站操作。

## 2026.07.15

外场调参。

由于风比较大，就没有使用 AutoTune。手动调参后效果并不好，最终 P 值调得过大，系统发散，导致炸机。

<https://ardupilot.org/copter/docs/autotune.html>

## 2026.07.29

好久没写日志了，我的仓库收到了来自很多学校同学的咨询和交流，这也是对我工作的认可，也是我后续继续开发的动力。

这一阵子主要做了好多地面测试，训练了新的视觉模型，新模型可能到国赛后才能开源。

地面端做了投放测试，用视觉伺服，测试通过。

然后就是最最最头疼的坐标变换问题，参考去年的代码，用以下方法：

这个问题的本质是 **飞控航向、ROS 本地坐标和程序目标方向采用了不同的坐标定义**：飞控的 `compass_hdg` 以正北为 0°、顺时针增加，而 MAVROS 的本地位置目标通常按 ENU 表达，以正东为 `+X`、正北为 `+Y`，偏航角以正东为 0°、逆时针增加，因此必须用 `yaw_ENU = 90° - compass_hdg` 进行转换；旧程序直接把姿态四元数写成 `(0,0,0,1)`，这并不是“忽略航向”，而是明确指定 ENU 偏航为 0°，即机头朝东，同时航点又从 `(0,0)` 飞向 `(5,0)`，等于沿 `+X` 向东移动，所以表现为飞机总是朝东或向东飞。新程序虽然会读取并锁定飞机当前航向，但如果在飞机朝东时过早锁定，锁定后又转动或搬动飞机，或者飞控因罗盘安装方向、校准、磁干扰或 EKF 航向估计错误而把实际方向报告成东，起飞后仍会按照错误的东向航向或旧位置进行修正。

## 2026.07.30

振奋人心的一天，完成了锁头和视觉代码的双重室外验证。锁头程序非常完美，这体现了学好 ROS ENU、四元数的重要性；室外视觉通过调整曝光程度，达到了比较好的效果。今晚赶一下，把单投放和全流程程序写出来。

## 2026.08.01

凌晨，昨天完成了 [`takeoff_drop_land_node_2.cpp`](https://github.com/Accelerate11/2026CUADC/blob/main/code/2026code/%E7%8A%B6%E6%80%81%E6%9C%BA/takeoff_drop_land_node_2.cpp) 代码的实验，初始问题在：

1. 工作空间与安装问题：目录多套一层，Python 视觉节点一度未安装到 libexec。
2. 地面状态异常：`/mavros/extended_state` 一直是 `ground=no`，导致状态机无法进入任务，后来已绕过起飞前该门禁。
3. 核心故障是 odom 断流：自动解锁和起飞成功后，`/mavros/local_position/odom` 超时，状态机立即切换降落。
4. 视觉与 odom 时间不同步：持续出现 `No bracketing odom`，视觉帧无法转换到飞控坐标系。
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

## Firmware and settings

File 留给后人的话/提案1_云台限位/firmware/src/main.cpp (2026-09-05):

#include "app_config.h"
#include "attitude_filter.h"
#include "gimbal_controller.h"
#include "icm42688.h"
#include "serial_protocol.h"
#include "servo_pwm.h"

#include "stm32g4xx_hal.h"

#include <cmath>

namespace {
SPI_HandleTypeDef g_spi1{};
UART_HandleTypeDef g_uart1{};
TIM_HandleTypeDef g_tim2{};
TIM_HandleTypeDef g_tim6{};
volatile uint32_t g_control_ticks = 0U;

void failFast() {
    __disable_irq();
    while (true) {}
}

void systemClockInit() {
    RCC_OscInitTypeDef osc{};
    RCC_ClkInitTypeDef clk{};

    (void)HAL_PWREx_ControlVoltageScaling(PWR_REGULATOR_VOLTAGE_SCALE1_BOOST);
    osc.OscillatorType = RCC_OSCILLATORTYPE_HSI;
    osc.HSIState = RCC_HSI_ON;
    osc.HSICalibrationValue = RCC_HSICALIBRATION_DEFAULT;
    osc.PLL.PLLState = RCC_PLL_ON;
    osc.PLL.PLLSource = RCC_PLLSOURCE_HSI;
    osc.PLL.PLLM = RCC_PLLM_DIV4;
    osc.PLL.PLLN = 85U;
    osc.PLL.PLLP = RCC_PLLP_DIV2;
    osc.PLL.PLLQ = RCC_PLLQ_DIV2;
    osc.PLL.PLLR = RCC_PLLR_DIV2;
    if (HAL_RCC_OscConfig(&osc) != HAL_OK) failFast();

    clk.ClockType = RCC_CLOCKTYPE_HCLK | RCC_CLOCKTYPE_SYSCLK |
                    RCC_CLOCKTYPE_PCLK1 | RCC_CLOCKTYPE_PCLK2;
    clk.SYSCLKSource = RCC_SYSCLKSOURCE_PLLCLK;
    clk.AHBCLKDivider = RCC_SYSCLK_DIV1;
    clk.APB1CLKDivider = RCC_HCLK_DIV1;
    clk.APB2CLKDivider = RCC_HCLK_DIV1;
    if (HAL_RCC_ClockConfig(&clk, FLASH_LATENCY_4) != HAL_OK) failFast();
}

void gpioInit() {
    __HAL_RCC_GPIOA_CLK_ENABLE();
    __HAL_RCC_GPIOB_CLK_ENABLE();
    __HAL_RCC_GPIOC_CLK_ENABLE();

    GPIO_InitTypeDef gpio{};
    gpio.Pin = GPIO_PIN_6;
    gpio.Mode = GPIO_MODE_OUTPUT_PP;
    gpio.Pull = GPIO_NOPULL;
    gpio.Speed = GPIO_SPEED_FREQ_VERY_HIGH;
    HAL_GPIO_Init(GPIOB, &gpio);
    HAL_GPIO_WritePin(GPIOB, GPIO_PIN_6, GPIO_PIN_SET);

    gpio.Pin = GPIO_PIN_5 | GPIO_PIN_6 | GPIO_PIN_7;
    gpio.Mode = GPIO_MODE_AF_PP;
    gpio.Pull = GPIO_NOPULL;
    gpio.Speed = GPIO_SPEED_FREQ_VERY_HIGH;
    gpio.Alternate = GPIO_AF5_SPI1;
    HAL_GPIO_Init(GPIOA, &gpio);

    gpio.Pin = GPIO_PIN_0 | GPIO_PIN_1;
    gpio.Mode = GPIO_MODE_AF_PP;
    gpio.Pull = GPIO_NOPULL;
    gpio.Speed = GPIO_SPEED_FREQ_HIGH;
    gpio.Alternate = GPIO_AF1_TIM2;
    HAL_GPIO_Init(GPIOA, &gpio);

    gpio.Pin = GPIO_PIN_2 | GPIO_PIN_3;
    gpio.Mode = GPIO_MODE_AF_PP;
    gpio.Pull = GPIO_NOPULL;
    gpio.Speed = GPIO_SPEED_FREQ_HIGH;
    gpio.Alternate = GPIO_AF12_LPUART1;
    HAL_GPIO_Init(GPIOA, &gpio);
}

void spiInit() {
    __HAL_RCC_SPI1_CLK_ENABLE();
    g_spi1.Instance = SPI1;
    g_spi1.Init.Mode = SPI_MODE_MASTER;
    g_spi1.Init.Direction = SPI_DIRECTION_2LINES;
    g_spi1.Init.DataSize = SPI_DATASIZE_8BIT;
    g_spi1.Init.CLKPolarity = SPI_POLARITY_LOW;
    g_spi1.Init.CLKPhase = SPI_PHASE_1EDGE;
    g_spi1.Init.NSS = SPI_NSS_SOFT;
    g_spi1.Init.BaudRatePrescaler = SPI_BAUDRATEPRESCALER_16;
    g_spi1.Init.FirstBit = SPI_FIRSTBIT_MSB;
    g_spi1.Init.TIMode = SPI_TIMODE_DISABLE;
    g_spi1.Init.CRCCalculation = SPI_CRCCALCULATION_DISABLE;
    g_spi1.Init.CRCPolynomial = 7U;
    g_spi1.Init.CRCLength = SPI_CRC_LENGTH_DATASIZE;
    g_spi1.Init.NSSPMode = SPI_NSS_PULSE_DISABLE;
    if (HAL_SPI_Init(&g_spi1) != HAL_OK) failFast();
}

void uartInit() {
    __HAL_RCC_LPUART1_CLK_ENABLE();
    g_uart1.Instance = LPUART1;
    g_uart1.Init.BaudRate = config::kUartBaud;
    g_uart1.Init.WordLength = UART_WORDLENGTH_8B;
    g_uart1.Init.StopBits = UART_STOPBITS_1;
    g_uart1.Init.Parity = UART_PARITY_NONE;
    g_uart1.Init.Mode = UART_MODE_TX_RX;
    g_uart1.Init.HwFlowCtl = UART_HWCONTROL_NONE;
    g_uart1.Init.OverSampling = UART_OVERSAMPLING_16;
    g_uart1.Init.OneBitSampling = UART_ONE_BIT_SAMPLE_DISABLE;
    g_uart1.AdvancedInit.AdvFeatureInit = UART_ADVFEATURE_NO_INIT;
    if (HAL_UART_Init(&g_uart1) != HAL_OK) failFast();
    HAL_NVIC_SetPriority(LPUART1_IRQn, 2U, 0U);
    HAL_NVIC_EnableIRQ(LPUART1_IRQn);
}

void pwmTimerInit() {
    __HAL_RCC_TIM2_CLK_ENABLE();
    g_tim2.Instance = TIM2;
    g_tim2.Init.Prescaler = 169U; // 170 MHz / 170 = 1 MHz
    g_tim2.Init.CounterMode = TIM_COUNTERMODE_UP;
    g_tim2.Init.Period = config::kServoPeriodUs - 1U;
    g_tim2.Init.ClockDivision = TIM_CLOCKDIVISION_DIV1;
    g_tim2.Init.AutoReloadPreload = TIM_AUTORELOAD_PRELOAD_ENABLE;
    if (HAL_TIM_PWM_Init(&g_tim2) != HAL_OK) failFast();

    TIM_OC_InitTypeDef channel{};
    channel.OCMode = TIM_OCMODE_PWM1;
    channel.Pulse = 1500U;
    channel.OCPolarity = TIM_OCPOLARITY_HIGH;
    channel.OCFastMode = TIM_OCFAST_DISABLE;
    if (HAL_TIM_PWM_ConfigChannel(&g_tim2, &channel, TIM_CHANNEL_1) != HAL_OK ||
        HAL_TIM_PWM_ConfigChannel(&g_tim2, &channel, TIM_CHANNEL_2) != HAL_OK) failFast();
}

void controlTimerInit() {
    __HAL_RCC_TIM6_CLK_ENABLE();
    g_tim6.Instance = TIM6;
    g_tim6.Init.Prescaler = 169U;
    g_tim6.Init.CounterMode = TIM_COUNTERMODE_UP;
    g_tim6.Init.Period = 2000U - 1U; // 500 Hz
    g_tim6.Init.AutoReloadPreload = TIM_AUTORELOAD_PRELOAD_DISABLE;
    if (HAL_TIM_Base_Init(&g_tim6) != HAL_OK) failFast();
    HAL_NVIC_SetPriority(TIM6_DAC_IRQn, 1U, 0U);
    HAL_NVIC_EnableIRQ(TIM6_DAC_IRQn);
}

bool stationaryForCalibration(const ImuSample& sample) {
    const float norm = std::sqrt(sample.accel_x_g * sample.accel_x_g +
                                 sample.accel_y_g * sample.accel_y_g +
                                 sample.accel_z_g * sample.accel_z_g);
    return std::fabs(norm - 1.0F) <= config::kCalibrationAccelToleranceG &&
           std::fabs(sample.gyro_x_dps) <= config::kCalibrationMaxGyroDps &&
           std::fabs(sample.gyro_y_dps) <= config::kCalibrationMaxGyroDps &&
           std::fabs(sample.gyro_z_dps) <= config::kCalibrationMaxGyroDps;
}

bool validGains(const Command& command) {
    return command.a > 0.0F && command.a <= 20.0F &&
           command.b > 0.0F && command.b <= 10.0F &&
           command.c >= 10.0F && command.c <= 300.0F &&
           command.d >= 10.0F && command.d <= 500.0F;
}
} // namespace

extern "C" void SysTick_Handler() { HAL_IncTick(); }
extern "C" void LPUART1_IRQHandler() { HAL_UART_IRQHandler(&g_uart1); }
extern "C" void TIM6_DAC_IRQHandler() { HAL_TIM_IRQHandler(&g_tim6); }
extern "C" void HAL_TIM_PeriodElapsedCallback(TIM_HandleTypeDef* timer) {
    if (timer->Instance == TIM6) ++g_control_ticks;
}

int main() {
    HAL_Init();
    systemClockInit();
    gpioInit();
    spiInit();
    uartInit();
    pwmTimerInit();
    controlTimerInit();

    SerialProtocol serial(g_uart1);
    ServoPwm roll_servo(g_tim2, TIM_CHANNEL_1, config::kRollMinPulseUs,
                        config::kRollCenterPulseUs, config::kRollMaxPulseUs);
    ServoPwm pitch_servo(g_tim2, TIM_CHANNEL_2, config::kPitchMinPulseUs,
                         config::kPitchCenterPulseUs, config::kPitchMaxPulseUs);
    Icm42688 imu(g_spi1, GPIOB, GPIO_PIN_6);
    AttitudeFilter filter;
    GimbalController controller;

    serial.begin();
    (void)roll_servo.begin();
    (void)pitch_servo.begin();
    controller.reset();

    SystemState system_state = SystemState::Boot;
    if (!imu.begin()) {
        system_state = SystemState::Fault;
        serial.sendError("IMU_INIT");
    } else {
        system_state = SystemState::Calibrating;
        serial.sendLine("INFO,CALIBRATION_KEEP_STILL");
    }

    if (HAL_TIM_Base_Start_IT(&g_tim6) != HAL_OK) failFast();

    uint32_t processed_tick = 0U;
    uint32_t calibration_count = 0U;
    float gyro_sum_x = 0.0F;
    float gyro_sum_y = 0.0F;
    float gyro_sum_z = 0.0F;
    float gyro_bias_x = 0.0F;
    float gyro_bias_y = 0.0F;
    float gyro_bias_z = 0.0F;
    uint32_t consecutive_imu_failures = 0U;
    AttitudeState attitude{};
    ServoAngles servo{};

    while (true) {
        Command command{};
        if (serial.poll(command)) {
            switch (command.type) {
            case CommandType::Arm:
                if (system_state == SystemState::Ready) {
                    controller.reset(roll_servo.angleDeg(), pitch_servo.angleDeg());
                    system_state = SystemState::Armed;
                    serial.sendAck("ARM");
                } else serial.sendError("NOT_READY");
                break;
            case CommandType::Disarm:
                if (system_state == SystemState::Armed) system_state = SystemState::Ready;
                serial.sendAck("DISARM");
                break;
            case CommandType::SetTarget:
                controller.setTarget(command.a, command.b);
                serial.sendAck("SET");
                break;
            case CommandType::Zero:
                if (system_state == SystemState::Ready &&
                    std::fabs(attitude.roll_rate_dps) < 2.0F &&
                    std::fabs(attitude.pitch_rate_dps) < 2.0F &&
                    std::fabs(attitude.accel_norm_g - 1.0F) < 0.05F) {
                    filter.setCurrentAsLevel();
                    serial.sendAck("ZERO");
                } else serial.sendError("ZERO_REQUIRES_STILL_DISARMED");
                break;
            case CommandType::SetRollGains:
            case CommandType::SetPitchGains:
                if (system_state != SystemState::Ready) serial.sendError("GAIN_REQUIRES_READY");
                else if (!validGains(command)) serial.sendError("GAIN_RANGE");
                else {
                    AxisGains gains{command.a, command.b, command.c, command.d};
                    if (command.type == CommandType::SetRollGains) controller.setRollGains(gains);
                    else controller.setPitchGains(gains);
                    serial.sendAck("GAIN");
                }
                break;
            case CommandType::Status:
                serial.sendTelemetry(system_state, attitude, servo, consecutive_imu_failures);
                break;
            case CommandType::Invalid:
                serial.sendError("BAD_COMMAND");
                break;
            default:
                break;
            }
        }

        const uint32_t available_tick = g_control_ticks;
        if (processed_tick == available_tick) continue;
        if (available_tick - processed_tick > 1U) processed_tick = available_tick - 1U;
        ++processed_tick;

        ImuSample sample{};
        if (!imu.read(sample, processed_tick * 2000U)) {
            ++consecutive_imu_failures;
            if (consecutive_imu_failures >= config::kMaxConsecutiveImuFailures) {
                system_state = SystemState::Fault;
                roll_servo.hold();
                pitch_servo.hold();
                if (consecutive_imu_failures == config::kMaxConsecutiveImuFailures) {
                    serial.sendError("IMU_READ");
                }
            }
            if (processed_tick % (config::kControlRateHz / config::kTelemetryRateHz) == 0U) {
                serial.sendTelemetry(system_state, attitude, servo, consecutive_imu_failures);
            }
            continue;
        }
        consecutive_imu_failures = 0U;

        if (system_state == SystemState::Calibrating) {
            if (!stationaryForCalibration(sample)) {
                calibration_count = 0U;
                gyro_sum_x = gyro_sum_y = gyro_sum_z = 0.0F;
            } else {
                gyro_sum_x += sample.gyro_x_dps;
                gyro_sum_y += sample.gyro_y_dps;
                gyro_sum_z += sample.gyro_z_dps;
                ++calibration_count;
                if (calibration_count >= config::kGyroCalibrationSamples) {
                    const float count = static_cast<float>(calibration_count);
                    gyro_bias_x = gyro_sum_x / count;
                    gyro_bias_y = gyro_sum_y / count;
                    gyro_bias_z = gyro_sum_z / count;
                    filter = AttitudeFilter{};
                    system_state = SystemState::Ready;
                    serial.sendLine("INFO,READY");
                }
            }
        }

        sample.gyro_x_dps -= gyro_bias_x;
        sample.gyro_y_dps -= gyro_bias_y;
        sample.gyro_z_dps -= gyro_bias_z;
        attitude = filter.update(sample, 1.0F / static_cast<float>(config::kControlRateHz));

        if (system_state == SystemState::Armed) {
            servo = controller.update(attitude, 1.0F / static_cast<float>(config::kControlRateHz));
            if (processed_tick % (config::kControlRateHz / config::kServoRateHz) == 0U) {
                roll_servo.setAngle(servo.roll_deg);
                pitch_servo.setAngle(servo.pitch_deg);
            }
        } else {
            servo.roll_deg = roll_servo.angleDeg();
            servo.pitch_deg = pitch_servo.angleDeg();
        }

        if (processed_tick % (config::kControlRateHz / config::kTelemetryRateHz) == 0U) {
            serial.sendTelemetry(system_state, attitude, servo, consecutive_imu_failures);
        }
    }
}

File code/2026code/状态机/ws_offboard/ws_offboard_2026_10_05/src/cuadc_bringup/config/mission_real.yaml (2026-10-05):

cuadc_full_mission_node:
  ros__parameters:
    # 部署开关；完成飞机检查后才应设为 true。
    flight_enable: true
    bucket_detection_topic: /perception/drop_buckets_body
    bucket_projection_log_path: ""
    lock_mission_yaw_to_initial_heading: true
    # 启动器在运行时注入航向 YAML 的角度；-1 是无效占位值，
    # 因此未提供航向的直接启动无法通过配置检查。
    geographic_heading_deg: -1.0
    yaw_to_target: false
    auto_arm_on_guided: true
    drop_only_mode: false
    # 试验配置：使用冻结的桶粗定位坐标，在 1.8 m 高度释放。
    coarse_release_trial_mode: true
    fixed_release_test_mode: false
    fixed_release_points_field_xy: [32.5, -2.6, 32.5, 2.6]

    vision_heartbeat_timeout_s: 1.5
    vision_max_pipeline_delay_s: 1.5
    vision_future_tolerance_s: 0.05
    vision_transform_tolerance_s: 0.20
    nav_interpolation_max_gap_s: 0.50
    odom_history_s: 5.0
    vision_pending_buffer_s: 1.00
    # 空检测帧也计为有效的起飞前视觉心跳。
    vision_min_messages_before_takeoff: 3
    search_vision_acquire_min_frames: 3
    search_vision_acquire_timeout_s: 5.0

    takeoff_alt_m: 3.0
    enforce_final_drop_heights: false
    search_alt_m: 3.0
    coarse_alt_m: 2.0
    fine_alt_m: 0.8
    transit_speed_m_s: 10.5
    drop_target_transit_speed_m_s: 6.0
    recon_transit_speed_m_s: 9.5
    return_speed_m_s: 11.0
    return_alt_m: 2.5
    search_speed_m_s: 1.75
    search_forward_step_m: 2.5
    recon_speed_m_s: 1.5
    drop_approach_speed_m_s: 5.0
    descent_vertical_speed_m_s: 0.2
    alignment_horizontal_speed_m_s: 0.5
    release_positioning_speed_m_s: 0.2
    release_stabilization_s: 2.0
    release_visual_xy_tolerance_m: 0.03
    middle_calibration_error_m: 0.12
    middle_calibration_stable_s: 0.50
    min_segment_time_s: 1.0
    waypoint_accept_radius_m: 0.40

    # 场地坐标相对于切入 GUIDED 时锁定的起点和航向。
    drop_area_near_edge_field_x_m: 30.0
    drop_area_length_field_x_m: 3.5
    drop_area_width_field_y_m: 8.0
    search_lane_count: 3
    cross_track_camera_fov_deg: 42.0
    search_lane_overlap_ratio: 0.30
    search_edge_margin_m: 0.35
    search_cross_margin_m: 0.55
    # 0 表示重复航线，直到生成可用的视觉投放方案。
    max_search_passes: 0

    # 危险物区域只执行航点覆盖，不接收危险物视觉输入。
    recon_area_center_field_x_m: 57.45
    recon_area_length_field_x_m: 2.4
    recon_area_width_field_y_m: 8.0
    recon_hover_alt_m: 2.0
    recon_lane_count: 2
    recon_edge_margin_m: 0.35
    recon_cross_margin_m: 0.55
    recon_waypoint_hold_s: 0.0

    bucket_required_count: 2
    use_post_search_cluster_fit: false
    cluster_position_scale_m: 0.60
    cluster_diameter_scale_m: 0.025
    motion_compensation_enabled: false
    motion_compensation_matrix: [0.85335529, 0.80596326, -0.97181809, 0.97507692]
    motion_compensation_reference_field_xy: [31.75, 0.0]
    # 已标定的实际桶直径：15 cm 和 20 cm。
    bucket_diameter_centers_m: [0.150, 0.200, 0.235]
    bucket_min_confirmations: 3
    track_gate_m: 0.45
    diameter_track_gate_m: 0.08
    bucket_track_max_gap_s: 0.60
    bucket_selection_max_age_s: 10.0
    bucket_distinct_min_separation_m: 0.14
    bucket_distinct_min_diameter_m: 0.025
    bucket_target_ranking_stable_s: 0.80
    bucket_diameter_filter_window: 9
    known_bucket_memory_s: 120.0
    released_bucket_exclusion_m: 0.25
    bucket_position_filter_alpha: 0.25
    bucket_body_filter_alpha: 1.0
    bucket_diameter_filter_alpha: 0.20
    bucket_confidence_filter_alpha: 0.30
    bucket_max_position_deviation_m: 0.25
    bucket_max_diameter_deviation_m: 0.050
    bucket_min_track_confidence: 0.25

    coarse_error_m: 0.15
    fine_error_m: 0.08
    coarse_stable_s: 0.8
    alignment_timeout_s: 12.0
    detection_timeout_s: 3.0
    target_guidance_max_age_s: 0.5
    recover_hold_s: 0.5

    prestream_hold_s: 1.5
    takeoff_timeout_s: 60.0
    # 此超时已关闭；下方的投放阶段超时从首次搜索开始计时。
    mission_timeout_s: 0.0
    drop_phase_timeout_s: 150.0
    return_climb_timeout_s: 30.0
    return_home_timeout_s: 120.0
    land_timeout_s: 120.0
    disarm_timeout_s: 20.0
    odom_timeout_s: 1.5
    compass_timeout_s: 1.0
    extended_state_timeout_s: 2.5
    landing_confirm_stable_s: 1.5
    landing_max_relative_altitude_m: 0.30
    landing_max_horizontal_speed_m_s: 0.20
    landing_max_vertical_speed_m_s: 0.15
    heading_lock_stability_s: 2.0
    heading_lock_max_variation_deg: 2.0
    position_lock_stability_s: 2.0
    stationary_speed_max_m_s: 0.15

    release_mode: servo
    payload_count: 2
    payload_release_offsets_body_m:
      # FCU FRD: 1号右前 (+x,+y), 2号左后 (-x,-y); +Z points down.
       [0.029, 0.070, 0.320,
       -0.031, -0.065, 0.320]
    servo_channels: [7, 8]
    servo_stowed_pwm: [1100, 1100]
    servo_release_pwm: [1900, 1900]
    servo_release_duration_s: [0.7, 0.7]
    servo_initialize_stowed: true
    servo_return_to_stowed: true
    servo_ack_timeout_s: 3.0
    virtual_release_ack_timeout_s: 3.0
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

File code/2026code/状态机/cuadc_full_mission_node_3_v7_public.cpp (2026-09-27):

/*
 * 视觉任务状态机公开参考版
 *
 * 说明：
 * 1. 本文件根据项目完整状态机整理为适合公开仓库展示的参考实现。
 * 2. 公开版保留 ROS2/MAVROS 接口、任务阶段、状态机、安全接管和模块边界。
 * 3. 公开版主动移除了比赛版本中的关键实现细节，包括但不限于：
 *    - 视觉帧与导航历史的精确时间对齐策略；
 *    - 多目标轨迹融合、重绑定、置信度融合与目标排序策略；
 *    - 搜索航线和侦察航线的真实生成方法及现场参数；
 *    - 投放口刚体几何补偿、姿态补偿、延迟预测和精对准闭环；
 *    - 比赛实测门限、速度曲线、机构外参和舵机参数。
 * 4. 被隐藏的部分只保留“输入、输出、功能目标和调用位置”，便于读者理解总体思路。
 * 5. 本文件默认关闭自动飞行和真实载荷动作，不能直接作为比赛或真实飞行程序使用。
 *
 * 许可证：请以公开仓库根目录中的 LICENSE 文件为准。
 */

#include <algorithm>
#include <array>
#include <chrono>
#include <cmath>
#include <cstdint>
#include <deque>
#include <future>
#include <functional>
#include <limits>
#include <memory>
#include <optional>
#include <string>
#include <utility>
#include <vector>

#include <geometry_msgs/msg/point_stamped.hpp>
#include <geometry_msgs/msg/pose_array.hpp>
#include <geometry_msgs/msg/pose_stamped.hpp>
#include <mavros_msgs/msg/state.hpp>
#include <mavros_msgs/srv/command_bool.hpp>
#include <mavros_msgs/srv/command_long.hpp>
#include <mavros_msgs/srv/command_tol.hpp>
#include <nav_msgs/msg/odometry.hpp>
#include <rclcpp/rclcpp.hpp>
#include <std_msgs/msg/bool.hpp>
#include <std_msgs/msg/float64.hpp>
#include <std_msgs/msg/u_int32.hpp>

using namespace std::chrono_literals;

namespace
{

constexpr double kPi = 3.14159265358979323846;
constexpr const char * kPublicVersion = "public-reference-2026";

using SteadyClock = std::chrono::steady_clock;
using SteadyTimePoint = SteadyClock::time_point;

struct Point3
{
  double x = 0.0;
  double y = 0.0;
  double z = 0.0;
};

struct Segment
{
  Point3 start;
  Point3 end;
  SteadyTimePoint start_time;
  double duration_s = 1.0;
};

struct PublicTrack
{
  std::size_t id = 0U;
  Point3 local;
  std::size_t confirmations = 0U;
  SteadyTimePoint last_seen;
};

enum class State
{
  WAIT_FCU,
  WAIT_NAV_STABLE,
  PRESTREAM,
  WAIT_GUIDED,
  WAIT_ARM,
  TAKEOFF,
  SEARCH,
  ALIGN_COARSE,
  ALIGN_FINE,
  RELEASE,
  RECON_TRANSIT,
  RECON_DESCEND,
  RECON_SCAN,
  RECON_RETURN,
  RETURN_HOME,
  LAND,
  DISARM,
  DONE,
  PILOT_OVERRIDE,
  ABORT
};

enum class ServoPurpose
{
  RELEASE,
  STOW
};

struct PendingServoCommand
{
  ServoPurpose purpose = ServoPurpose::RELEASE;
  std::size_t payload = 0U;
  SteadyTimePoint sent;
  rclcpp::Client<mavros_msgs::srv::CommandLong>::SharedFuture future;
};

double normalize_angle(double value)
{
  return std::atan2(std::sin(value), std::cos(value));
}

double normalize_degrees(double value)
{
  value = std::fmod(value, 360.0);
  return value < 0.0 ? value + 360.0 : value;
}

double distance_xy(const Point3 & a, const Point3 & b)
{
  return std::hypot(a.x - b.x, a.y - b.y);
}

double distance_xyz(const Point3 & a, const Point3 & b)
{
  return std::hypot(distance_xy(a, b), a.z - b.z);
}

}  // 命名空间结束

class VisualMissionPublicNode final : public rclcpp::Node
{
public:
  VisualMissionPublicNode()
  : Node("visual_mission_public_node")
  {
    declare_parameters();
    load_parameters();

    state_sub_ = create_subscription<mavros_msgs::msg::State>(
      "/mavros/state", rclcpp::QoS(10).reliable(),
      std::bind(&VisualMissionPublicNode::state_callback, this, std::placeholders::_1));

    odom_sub_ = create_subscription<nav_msgs::msg::Odometry>(
      "/mavros/local_position/odom", rclcpp::SensorDataQoS(),
      std::bind(&VisualMissionPublicNode::odom_callback, this, std::placeholders::_1));

    compass_sub_ = create_subscription<std_msgs::msg::Float64>(
      "/mavros/global_position/compass_hdg", rclcpp::SensorDataQoS(),
      std::bind(&VisualMissionPublicNode::compass_callback, this, std::placeholders::_1));

    bucket_sub_ = create_subscription<geometry_msgs::msg::PoseArray>(
      bucket_topic_, rclcpp::SensorDataQoS(),
      std::bind(&VisualMissionPublicNode::bucket_callback, this, std::placeholders::_1));

    recon_ack_sub_ = create_subscription<std_msgs::msg::UInt32>(
      "/cuadc/recon/capture_done", 10,
      std::bind(&VisualMissionPublicNode::recon_ack_callback, this, std::placeholders::_1));

    setpoint_pub_ = create_publisher<geometry_msgs::msg::PoseStamped>(
      "/mavros/setpoint_position/local", 10);

    recon_photo_mode_pub_ = create_publisher<std_msgs::msg::Bool>(
      "/cuadc/recon/photo_mode", 10);

    recon_capture_pub_ = create_publisher<geometry_msgs::msg::PointStamped>(
      "/cuadc/recon/capture_request", 10);

    takeoff_client_ = create_client<mavros_msgs::srv::CommandTOL>("/mavros/cmd/takeoff");
    land_client_ = create_client<mavros_msgs::srv::CommandTOL>("/mavros/cmd/land");
    arm_client_ = create_client<mavros_msgs::srv::CommandBool>("/mavros/cmd/arming");
    command_client_ = create_client<mavros_msgs::srv::CommandLong>("/mavros/cmd/command");

    const auto now_steady = SteadyClock::now();
    state_enter_time_ = now_steady;
    mission_start_time_ = now_steady;
    last_odom_arrival_ = now_steady;
    last_compass_arrival_ = now_steady;
    last_request_time_ = now_steady - 2s;
    last_status_time_ = now_steady;

    timer_ = create_wall_timer(50ms, std::bind(&VisualMissionPublicNode::tick, this));

    RCLCPP_WARN(
      get_logger(),
      "公开参考版已启动 [%s]。默认关闭自动飞行和真实载荷动作，不能直接用于比赛飞行。",
      kPublicVersion);
  }
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

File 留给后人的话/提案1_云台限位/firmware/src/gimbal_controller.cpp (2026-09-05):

#include "gimbal_controller.h"

#include "app_config.h"

float GimbalController::clamp(float value, float low, float high) {
    return value < low ? low : (value > high ? high : value);
}

void GimbalController::reset(float roll_servo_deg, float pitch_servo_deg) {
    servo_.roll_deg = clamp(roll_servo_deg, config::kServoMinDeg, config::kServoMaxDeg);
    servo_.pitch_deg = clamp(pitch_servo_deg, config::kServoMinDeg, config::kServoMaxDeg);
}

void GimbalController::setTarget(float roll_deg, float pitch_deg) {
    target_roll_deg_ = clamp(roll_deg, -20.0F, 20.0F);
    target_pitch_deg_ = clamp(pitch_deg, -30.0F, 30.0F);
}

void GimbalController::setRollGains(const AxisGains& gains) { roll_gains_ = gains; }
void GimbalController::setPitchGains(const AxisGains& gains) { pitch_gains_ = gains; }

float GimbalController::stepAxis(float angle_error_deg, float measured_rate_dps,
                                 float dt_s, float direction, const AxisGains& gains,
                                 float current_servo_deg) {
    const float target_rate = clamp(gains.attitude_kp * angle_error_deg,
                                    -gains.max_target_rate_dps, gains.max_target_rate_dps);
    const float rate_error = target_rate - measured_rate_dps;
    const float servo_slew = clamp(gains.rate_kp * rate_error,
                                   -gains.max_servo_slew_dps, gains.max_servo_slew_dps);
    return clamp(current_servo_deg + direction * servo_slew * dt_s,
                 config::kServoMinDeg, config::kServoMaxDeg);
}

ServoAngles GimbalController::update(const AttitudeState& state, float dt_s) {
    dt_s = clamp(dt_s, 0.0005F, 0.02F);
    servo_.roll_deg = stepAxis(target_roll_deg_ - state.roll_deg, state.roll_rate_dps,
                               dt_s, config::kRollServoDirection, roll_gains_, servo_.roll_deg);
    servo_.pitch_deg = stepAxis(target_pitch_deg_ - state.pitch_deg, state.pitch_rate_dps,
                                dt_s, config::kPitchServoDirection, pitch_gains_, servo_.pitch_deg);
    return servo_;
}

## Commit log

2026-02-18 Add offboard control node for MAVROS
    Implement offboard control node for MAVROS with waypoint navigation and landing sequence.
2026-02-18 Update 技术全解
2026-02-18 Update 日志
2026-08-28 Fix formatting issues in 日志.md
    Updated log entries to correct formatting and improve clarity.
2026-08-28 Refine formatting and content in 日志.md
    Updated headings and removed duplicate content in 日志.md.
2026-08-28 Update log entry in 日志.md
2026-08-28 Revise log with testing details and observations
    Updated the log to include details about the camera testing and flight code logic, along with observations regarding flight direction and issues with visual code validation.
2026-09-02 Update comment header in cuadc_full_mission_node_3.cpp
    Removed '公开 / 社区版' from the comment header.
2026-09-04 Organize simulation projects under sim
    [cuadc_rescue_single.sdf, hazard_recognition_single.sdf, iris_collision.stl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]
2026-09-11 Add acknowledgment for HARD海砥装备 support
2026-09-26 Add section for 算法 in 技术全解.md
2026-10-08 Update year in 留给后人的一封信.md to 2026
2026-10-15 Rename camera and imaging document

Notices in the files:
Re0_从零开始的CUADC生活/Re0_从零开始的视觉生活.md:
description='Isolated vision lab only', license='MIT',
